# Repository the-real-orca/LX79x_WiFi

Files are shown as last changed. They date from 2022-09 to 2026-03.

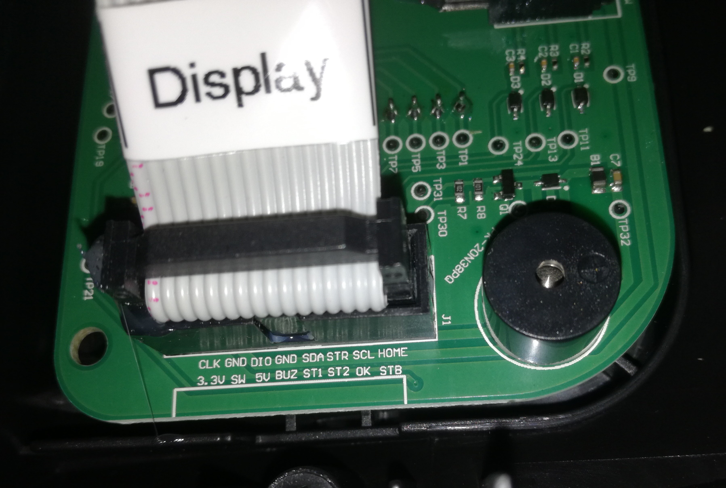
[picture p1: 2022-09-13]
pic/LX790 V1.1/DisplayPCB_1.jpg

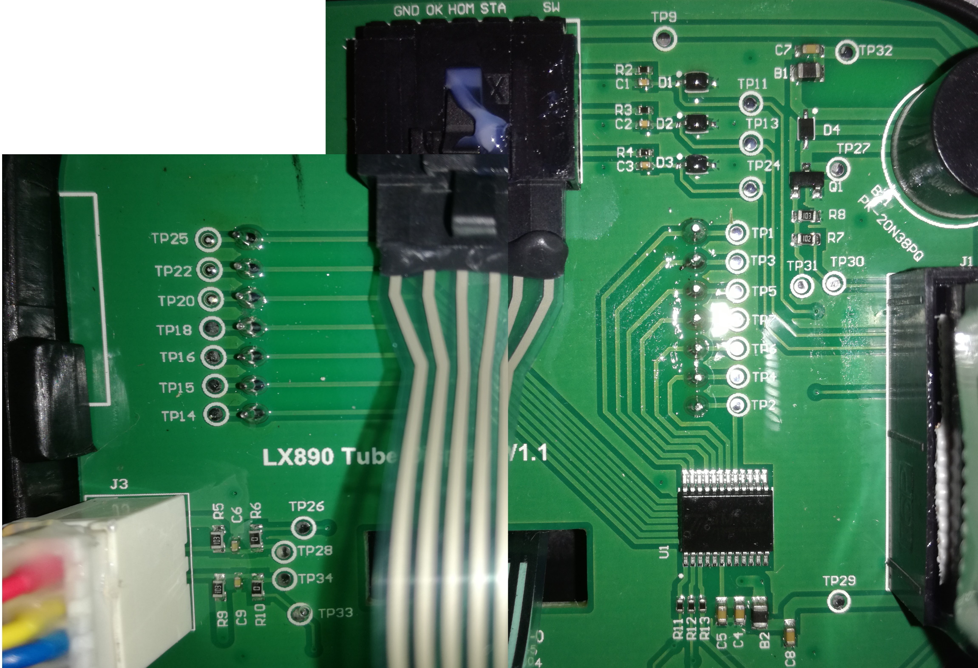
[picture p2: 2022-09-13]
pic/LX790 V1.1/DisplayPCB_2.jpg

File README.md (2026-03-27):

# LX79x Mähroboter WiFi Erweiterung mit ESP32

Nachrüstung einer WiFi Schnittstelle mit Websteuerung für einen LandXcape LX79x Mähroboter

*Der Einsatz von diesem Projekt erfolgt auf eigene Gefahr! Der Ersteller kann nicht für Schäden haftbar gemacht werden. Sie können einen Verlust der Garantie und des Supports durch den Hersteller riskieren! Dieses Projekt ist keine offizielle Erweiterung des Roboters!*

<p align="center">
  
  
</p>

### Allgemein
- Fernauslesen des Displays
- Klartextausgabe der Fehlercodes
- Fernsteuern der Tasten und Funktionen
- Anbindung über den I2C Bus zwischen Display und Mainboard
- Wenn der Roboter in der Ladestation steht uns aus ist, kann dieser mit "I/O" eingeschaltet werden

### Voraussetzungen
#### Hardware
Zum Einsatz kommt der ESP32 auf dem Board "DOIT ESP32 DEVKIT V1". Dieser wurde gewählt, da er zwei Hardware I2C Schnittstellen besitzt. Das ist wichtig, da beim I2C Bus des Roboters das Timing nicht zu sehr beeinflusst werden darf.

##### Anbindung an den I2C Bus
Um den ESP32 in den I2C Bus zwischen Mainboard und Display zwischenschalten zu können, benötigt man ein Adapterkabel. Dabei muss am Roboter selbst nichts "umgebaut" werden. Es wird lediglich der Stecker des Displays ausgesteckt und ein Adapter wie folgt dazwischen gesteckt:
<p align="center">
  
  
    
    
    
    
    
</p>

Das Adapterkabel hat eine Gesamtlänge von ca 70cm.

##### Platine
Der ESP32 wird auf eine Lochrasterplatine Adaptiert. Die fertige Platine kann dann in dem Batteriefach eingebaut werden.
<p align="center">
  
  
  
  
</p>

[Gesamter Schaltplan als PDF](pic/Schaltplan.pdf)

#### Software
Um den ESP32 programmieren und flashen zu können, wurde in diesem Projekt die Arduino IDE eingesetzt.

##### Folgende Voraussetzungen müssen dafür geschaffen werden:
1. Installation der aktuellen Arduino IDE
2. ESP32 Core installieren (https://docs.espressif.com/projects/arduino-esp32/en/latest/installing.html)
3. Boardtyp auswählen: 'Werkzeuge->Board->DOIT ESP32 DEVKIT V1'
4. CRC Bibliothek ergänzen: 'Werkzeuge->Bibliotheken verwalten...->CRC (Rob Tillaart)'
5. Filesystem Uploader: (https://randomnerdtutorials.com/install-esp32-filesystem-uploader-arduino-ide/)
  1. Download ESP32FS ZIP: https://github.com/me-no-dev/arduino-esp32fs-plugin/releases/
  2. ZIP direkt in "c:\Program Files (x86)\Arduino\tools\" entpacken
  3. Arduino IDE neu starten

##### ESP32 flashen/Programm und Daten uploaden:
1. Repository herunterladen und "ino" Projektdatei öffnen
2. ESP32 Board per USB verbinden und passende COM Schnittstelle auswählen: 'Werkzeuge->Port'
3. Im .ino Code die WiFi Zugangsdaten anpassen:
```c
const char* ssid     = "DEINESSID";
const char* password = "DEINPASSWORT";
```
4. Ordner "data" mit 'Werkzeuge->ESP32 Sketch Data Upload' hochladen
5. Seriellen Monitor öffnen
6. Projekt kompilieren und hochladen
7. Über Seriellen Monitor kontrollieren ob WiFi Verbindung besteht und IP Adresse, welche vom DHCP Server vergeben wurde, ermitteln bzw. merken.

### Anwendung
#### Webbrowser
Das Webinterface kann direkt mit der IP Adresse aufgerufen werden:
<p align="center">
  
</p>

#### HTTP Anfragemethoden
##### Befehle Senden
http://MOWERADRESS/cmd?parm=[COMMAND]&value=[VALUE]

param=[COMMAND]:

- start -> Taste Start bzw. hoch
- home -> Taste Home bzw. runter
- ok -> Taste Ok
- stop -> Taste Stop
- workzone -> Arbeitsbereich einstellen
- timedate -> Zeit und Datum einstellen
- startmow -> "Mähen" starten
- homemow -> "Zurück zur Ladestation" starten

value=[VALUE]:

- Bei "start, home, ok, stop" ist [VALUE] die Dauer in ms des Tastendrucks ansonsten muss 1 übergeben werden.

>Beispiel - die Taste Start soll 5 Sekunden gedrückt werden:
>
>http://MOWERADRESS/cmd?parm=start&value=5000

##### Zustand Abfragen
http://MOWERADRESS/statval

Antwort:
[Display];[RSSI];[Batteriestatus];[Klartext]

>Beispiel bei Fehler:
>
>-E8-;-83;off;Es dauert zu lange, bis der Robi zur Ladestation zurückkehrt.
>
>Beispiel während dem Mähen:
>
>|--|;-80;mid;Mähen...

##### Beispiel
Einbindung in FHEM per HTTPMOD:

```
defmod MRoboter HTTPMOD none 5
attr MRoboter alias MRoboter
attr MRoboter event-on-change-reading .*
attr MRoboter get01-1Name Display
attr MRoboter get01-2Name RSSI
attr MRoboter get01-3Name Battery
attr MRoboter get01-4Name Status
attr MRoboter get01Decode UTF-8
attr MRoboter get01Name Ouput
attr MRoboter get01Poll 1
attr MRoboter get01Regex (\N+);;(\N+);;(\N+);;(\N+)
attr MRoboter get01URL http://192.168.2.54:80/statval
attr MRoboter group Mähroboter
attr MRoboter room Haus
attr MRoboter showBody 1
attr MRoboter stateFormat D: Display WL: RSSI S: Status B: Battery
```

Eine Aufzeichnung sieht dann so aus:

<p align="center">
  
</p>

##### Update ausführen
http://MOWERADRESS/update

Damit kann eine .bin Datei auf den ESP32 hochgeladen werden.

---

### Entwicklung mit Docker
Für eine konsistente Build-Umgebung steht ein Docker-Setup zur Verfügung. Dies ist besonders nützlich, wenn man keine lokale Arduino IDE oder PlatformIO Installation pflegen möchte.

Details zur Einrichtung und Verwendung finden sich in der [docker_setup.md](docker_setup.md).

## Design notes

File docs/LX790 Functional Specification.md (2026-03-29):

# Funktionale Spezifikation (FSD) - LX790 WiFi Erweiterung

## 1. Übersicht

### 1.1 Zweck
Das LX790 WiFi Erweiterungsprojekt dient der Nachrüstung eines LandXcape LX79x Mähroboters mit einer WLAN-Schnittstelle. Ziel ist es, den Mähroboter aus der Ferne zu überwachen, zu steuern und in bestehende Smart-Home-Systeme zu integrieren.

### 1.2 Umfang
Enthalten sind die Echtzeit-Überwachung des Displays, die Fernsteuerung der Tasten, WLAN-Konnektivität und OTA-Updates. Ausgeschlossen ist der direkte Eingriff in die Motorsteuerung oder Sensordaten des Mähers.

### 1.3 Benutzer / Rollen
- Admin: Konfiguriert WLAN-Einstellungen und führt Firmware-Updates durch.
- Nutzer: Überwacht den Status des Mähers und nutzt die Fernsteuerung.

## 2. Funktionale Zusammenfassung

### 2.1 Hauptablauf / Betriebsmodi
- Normaler Modus: ESP32 ist mit dem Heim-WLAN verbunden und überträgt Daten.
- Konfigurations-Modus: Captive Portal zur Ersteinrichtung bei fehlender Verbindung.
- Debug-Modus: Erweiterte Protokollierung von Hardware-Signalen.

### 2.2 Systemarchitektur
```
┌──────────────────────────────────────────────────────────────────────────┐
│                          Netzwerk (WLAN)                                 │
└──────────────────────────────────────────────────────────────────────────┘
       │                                           │
       ▼                                           ▼
┌────────────────────────┐              ┌────────────────────┐
│  Mähroboter (LX790)    │              │  Benutzeroberfläche│
│  ┌──────────────────┐  │              └────────────────────┘
│  │ Display / Tasten │  │
│  └──────────────────┘  │
│          ▲             │
│          │ Sniffing    │
│  ┌──────────────────┐  │
│  │ ESP32 Erweiterung│  │
│  └──────────────────┘  │
└────────────────────────┘
```

### 2.3 Hardwarebeschreibung
- Zentraleinheit: ESP32 Mikrocontroller.
- Display-Schnittstelle: TM1668 Controller (3-Draht-SPI).
- Tasten-Interface: GPIO-Anbindung zur Simulation von Tastendrücken.

### 2.4 Kernkomponenten
- Display-Decoder: Dekodiert TM1668 Segmente in Klartext.
- Button-Injector: Steuert die GPIOs zur Tasten-Simulation.
- Web-Server: Stellt das Interface und die REST-API bereit.

## 3. Definitionen

### 3.1 Begriffe und Abkürzungen

| Name | Beschreibung |
|---|---|
| TM1668 | LED-Controller für Anzeige und Tasten. |
| Sniffing | Passives Mitlesen des Datenbusses. |
| OTA | Firmware-Update über WLAN (Over-the-Air). |

## 4. Funktionale Anforderungen

### 4.1 Status-Überwachung (FR-001)
Das System zeigt den aktuellen Inhalt des 7-Segment-Displays und die Symbole in Echtzeit an.

 - **Auslöser:** kontinuierlich

 - **Verhalten:**
   - Der ESP32 dekodiert die Segmente und Symbole (Batterie, Uhr, Schloss)
   - Der ESP32 aktualisiert den internen System-Status

 - **Erwartetes Ergebnis:**
   - Die Weboberfläche spiegelt den exakten Inhalt des physischen Displays wider

### 4.2 Fernsteuerung der Tasten (FR-002)
Simulation der Tasten Start, Home, OK und Stop.

 - **Auslöser:** Benutzerinteraktion in der Weboberfläche oder API-Aufruf.

 - **Verhalten:**
   - Der entsprechende GPIO wird kurzzeitig als Ausgang (LOW) geschaltet
   - Das System simuliert einen physischen Tastendruck

 - **Erwartetes Ergebnis:**
   - Der Mähroboter reagiert so, als wäre die physische Taste manuell gedrückt worden

### 4.3 Automatisches Entsperren (FR-003)
Automatische Eingabe des PIN-Codes, wenn der Mäher gesperrt ist.

 - **Auslöser:** Detektion des Sperr-Symbols oder des PIN-Eingabe-Displays ("0---").

 - **Verhalten:**
   - Das System prüft ob der Mäher automatisch entsperrt werden soll (`config.json`)
   - Wenn ja, liest es die hinterlegte PIN aus der Konfiguration
   - Das System sendet die PIN als Sequenz virtueller Tastendrücke

 - **Erwartetes Ergebnis:**
   - Der Mäher wechselt automatisch in den entsperrten Zustand

### 4.4 WLAN-Konfiguration (FR-004)
Verwaltung der WLAN-Zugangsdaten und des Captive Portals.

 - **Auslöser:** 
   - Erststart oder fehlende Verbindung zum Netzwerk.
   - press "HOME" button for 10 seconds to start captive portal

 - **Verhalten:**
   - Start des Access Points
   - DNS-Umleitung aller Anfragen zur Konfigurationsseite

 - **Erwartetes Ergebnis:**
   - Nutzer kann neue Zugangsdaten speichern und das System verbindet sich neu

## 5. Nicht-funktionale Anforderungen

### 5.1 Echtzeitfähigkeit (NFR-001)
Die Verzögerung zwischen physischem Display und Web-Anzeige muss minimal sein.

**Erwartetes Ergebnis:**
- Die Latenz der Statusaktualisierung liegt unter 500ms

### 5.2 Zuverlässigkeit (NFR-002)
Das System darf den normalen Betrieb des Mähers bei Fehlfunktion des ESP32 nicht stören.

**Erwartetes Ergebnis:**
- Der Mäher bleibt auch bei Ausfall des ESP32 manuell bedienbar

## 6. Daten
- Quelle: TM1668 Bus via ESP32 Sniffing
- Format: JSON Objekt via /status API
- Speicherung: Konfiguration in config.json auf SPIFFS

## 7. Benutzeroberfläche

### 7.1 Dashboard
Hauptseite zur Überwachung und Steuerung.
- Replikation des Displays
- Steuerungstasten und Makros
- Statusanzeigen für Batterie und System

## 8. Testfälle

### 8.1 Display-Replikation (TC-001)
1. Ändere den Zustand des Mähers (z.B. Stop drücken)
2. Überprüfe die Anzeige in der Weboberfläche

 - **Erfolgskriterien:**
   - Die Weboberfläche zeigt den korrekten Status (z.B. -E1-)

 - **Verknüpfte Anforderungen:** FR-001

### 8.2 Remote-Start (TC-002)
1. Betätige den Button "Mähen starten" in der Weboberfläche

 - **Erfolgskriterien:**
   - Der Mähroboter piept und startet den Mähvorgang

 - **Verknüpfte Anforderungen:** FR-002

## 9. Offene Punkte / Annahmen

### 9.1 Offene Fragen
- Ladeerkennung: Unterscheidung zwischen DOCKED und CHARGING unzuverlässig.
- Auto-Unlock: Validierung bei unterschiedlichen Firmware-Ständen des Mähers.

### 9.2 Annahmen
- Stabile Stromversorgung über die interne 5V Schiene.
- TM1668 Protokoll ist konsistent über die gesamte LX79x Serie.

## Anhang A: Technische Details
Detaillierte Informationen zur Architektur, den Quellcodedateien und der Pin-Belegung finden Sie in der technischen Spezifikation:
[LX790 Technical Specification.md](LX790%20Technical%20Specification.md)

## Anhang B: Implementierungsplan
Den aktuellen Status der Umsetzung sowie geplante Aufgaben finden Sie im Implementierungsstatus:
[LX790 Implementation Status.md](LX790%20Implementation%20Status.md)

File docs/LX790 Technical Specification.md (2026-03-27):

# Technical Specification - LX790 WiFi Extension

## 1. System Architecture
The system is built on an ESP32 microcontroller using the Arduino framework with FreeRTOS for multi-tasking. It intercepts the communication between the mower's mainboard and the display unit. It uses a dual-core approach to separate timing-critical hardware sniffing from the network stack.

### 1.1 Task Structure
The application is divided into two main FreeRTOS tasks pinned to different cores:

- **TaskHW (Core 0)**: 
    - Handles low-level hardware communication (TM1668 sniffing, button injection).
    - Manages WiFi connectivity (Station mode & Captive Portal).
    - Processes the command queue (`cmdQueue`).
    - Updates the system state and sends it to `stateQueue`.
- **TaskWeb (Core 1)**:
    - Hosts the asynchronous web server.
    - Serves static files from SPIFFS.
    - Provides a REST API for status monitoring and command execution.
    - Manages UI updates and system logging.

## 2. Source File Overview

| File | Description | Key Functions / Interfaces |
|---|---|---|
| `LX790_ESP32.ino` | Main entry point. Initializes Serial, SPIFFS, and launches FreeRTOS tasks. | `setup()`, `loop()` |
| `TaskHW.cpp` | Core logic for hardware interaction and WiFi management. | `TaskHW()`, manages `stateQueue` and `cmdQueue`. |
| `TaskWeb.cpp` | Implementation of the web server and REST API. | `TaskWeb()`, `Web_getCmd()`, `Web_aktStatusWeb()`, `jsonStatus()`. |
| `HAL_LX790.h` | Generic HAL interface. Includes version-specific headers. | `HAL_setup()`, `HAL_loop()`, `HAL_buttonPress()`, `HAL_buttonRelease()`. |
| `HAL_LX790_V1_0.cpp/h` | HAL for V1.0 hardware (using I2C sniffing). | Implements hardware communication for older models. |
| `HAL_LX790_V1_1.cpp/h` | HAL for V1.1 hardware (using TM1668 SPI sniffing). | TM1668 bit-banging and signal interception logic. |
| `LX790_util.cpp/h` | Utility functions for data decoding and command queueing. | `decodeChar()`, `encodeSeg()`, `decodeDisplay()`, `queueButton()`. |
| `FileBrowser.cpp/h` | SPIFFS file management for the web interface. | `handleFileRead()`, `handleFileUpload()`, `handleFileDelete()`. |
| `ahWireSlave.cpp/h` | Custom I2C slave driver for ESP32 (used in V1.0). | `TwoWireSlave::begin()`, `read_buff()`, `write_buff()`. |
| `config.h` | Global configuration, model selection, and debug flags. | `LX790_Config` struct, `HW_MODEL` define. |

## 3. Hardware Components

### 3.1 Microcontroller (ESP32)
- Dual-core 240MHz Xtensa® LX6.
- Integrated WiFi/Bluetooth.
- Utilizes SPIFFS for web resource storage and EEPROM/Preferences for persistent configuration.

### 3.2 Hardware Abstraction Layer (HAL)
A polymorphic HAL allows supporting different hardware versions (V1.0 and V1.1):
- `HAL_LX790_V1_0`: Original implementation using I2C slave mode to listen to display updates.
- `HAL_LX790_V1_1`: Updated pin mapping and logic for version 1.1 hardware using TM1668 SPI sniffing.

### 3.3 Display Controller Sniffing (TM1668)
The ESP32 "sniffs" the SPI-like protocol used by the TM1668 display controller:
- **Signals**: CLK (Clock), DIO (Data), STB (Chip Select).
- **Protocol**: 3-wire serial interface, LSB first.
- **Method**: The HAL identifies `DISPLAY_CMD_ADDRESS (0xC0)` to capture segment data for the 4 digits and additional symbols (Battery, Clock, Lock).

### 3.4 Button Injection
Remote control is achieved by pulling physical button lines to GND via ESP32 GPIOs:
- **Buttons**: Power/IO, Start (Up), Home (Down), OK, Stop.
- **Method**: GPIOs are configured as `INPUT` (high impedance) when inactive and `OUTPUT LOW` to simulate a press.

## 4. Communication & Data Flow

### 4.1 Inter-Task Communication
- **`stateQueue`**: A FreeRTOS queue (`QueueHandle_t`) used to push `LX790_State` updates from `TaskHW` (Core 0) to `TaskWeb` (Core 1).
- **`cmdQueue`**: A FreeRTOS queue used to send `CMD_Type` commands from the Web/Serial interface to the hardware task.
- **`queueButton(BUTTONS btn, int delay)`**: Helper function that sequences a `BTN_PRESS`, a `WAIT`, and a `BTN_RELEASE` into the `cmdQueue`.

### 4.2 External Interfaces
- **Web UI**: Responsive HTML/JS interface served from SPIFFS.
- **REST API**: 
    - `GET /status`: Returns full state as JSON (generated by `jsonStatus()`).
    - `GET /cmd?parm=[BTN]&value=[0/1]`: Executes button presses or system commands.
- **Serial Console**: 115200 baud, supports manual configuration (`config`), reboot, and WiFi mode switching (`portal`, `client`).

## 5. Software Stack
- **Framework**: Arduino ESP32.
- **JSON Library**: ArduinoJson (v7.x).
- **Web Server**: WebServer (built-in) / ESP32 Web Server logic.
- **Storage**: SPIFFS for files (Web UI, logs), EEPROM for settings (debugLog, autoUnlock).
- **Other**: DNSServer for Captive Portal, mDNS for hostname resolution, ezTime for NTP sync.

## 6. Pin Mapping (V1.1 Example)
| Function | ESP32 Pin | Signal | Cable Pin |
|---|---|---|---|
| CLK | D14 | Clock  | #2 |
| DIO | D13 | Data | #6 |
| STB | D15 | CS | #15 |
| OK | D33 | Button | #13 |
| START | D25 | Button | #12 |
| HOME | D32 | Button | #16 |
| STOP | D26 | Button | #9 & #11  |
| SW (IO)  | D27 | Button | #3 |

## 7. Implementation Details
- **TM1668 Decoding**: Raw segment data is converted into ASCII characters via a lookup table (`decodeChar`) in `LX790_util.cpp`.
- **Mode Detection**: The system analyzes display patterns and system flags to infer the mower's state (Mowing, Charging, Error, etc.).
- **Auto-Unlock**: A state machine in `TaskHW` can automatically sequence the PIN entry if the `lock` flag is detected on the display.
- **Logging**: `TaskWeb` manages rotating logs (`system.log`, `debug.log`) stored in SPIFFS, capturing state changes and debug information.

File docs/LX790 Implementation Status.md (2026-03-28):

# Abgleich FSD vs. Implementierung (LX790 WiFi Extension)

Diese Liste gibt einen Überblick über den Erfüllungsgrad der im Functional Specification Document (FSD) definierten Anforderungen.

## 1. Status-Überwachung
| Funktion | Status | Anmerkung |
|---|---|---|
| Display-Replikation | **OK** | 7-Segment Dekodierung in `LX790_util.cpp` implementiert. |
| Statussymbole (Uhr, Schloss) | **OK** | Symbole werden im Web UI und im State-Objekt korrekt verarbeitet. |
| WLAN-Status Symbol | **Entfällt** | Gemäß FSD (3.1) nicht angezeigt, da Web-Verbindung WLAN voraussetzt. |
| Batteriestand | **OK** | 4-stufige Anzeige im Web UI integriert. |
| Ladezustand (Laden) | **Fehlerhaft** | In `LX790_util.cpp:261` steht ein `FIXME`, das den Modus hart auf `DOCKED` überschreibt, da die Lade-Erkennung unzuverlässig ist. |
| Klartext-Status (Fehlercodes) | **OK** | Umfangreiche Mapping-Tabelle `LcdToMode` in `LX790_util.cpp`. |

## 2. Fernsteuerung
| Funktion | Status | Anmerkung |
|---|---|---|
| Virtuelle Tasten (Start, Home, OK, Stop) | **OK** | Alle Tasten über `/cmd?parm=...` erreichbar. |
| Makro "Mähen starten" | **OK** | START + OK Sequenz. |
| Makro "Zur Ladestation" | **OK** | HOME + OK Sequenz. |
| PIN Vergabe (Makro) | **OK** | START + HOME (8s) Makro zum Start der PIN-Änderung am Mäher. |

## 3. Konnektivität & Konfiguration
| Funktion | Status | Anmerkung |
|---|---|---|
| WLAN Client-Modus | **OK** | In `TaskHW.cpp` und `config.json` implementiert. |
| Captive Portal / AP | **OK** | In `TaskHW.cpp` und `config.json` implementiert. |
| Web-Interface | **OK** | Responsives UI (`index.html`, `config.html`) vorhanden. |
| mDNS Support | **OK** | `MDNS.begin()` mit konfigurierbarem Namen. |

## 3.4 System-Konfiguration (`config.html`)
| Funktion | Status | Anmerkung |
|---|---|---|
| Gerätename | **OK** | Hostname wird aus `config.json` geladen. |
| PIN-Hinterlegung | **OK** | PIN für Auto-Unlock wird in `config.json` gespeichert. |
| WLAN-Settings | **OK** | SSID/Passwort in `config.json`. |
| Portal-Settings | **OK** | Aktivierung, Passwort und Timeout in `config.json`. |

## 3.5 Betriebs- & Systemeinstellungen (`index.html`)
| Funktion | Status | Anmerkung |
|---|---|---|
| Auto-Unlock | **Teilweise** | Schalter vorhanden, Speicherung im EEPROM. PIN-Eingabe-Logik experimentell. |
| Mäher-Konfiguration | **OK** | Makros für Arbeitsbereich, Zeit/Datum, PIN-Änderung, Startzeit. |
| Reboot | **OK** | Über `/cmd?parm=reboot` möglich. |
| OTA-Updates | **OK** | Über `/update` implementiert. |
| Dateisystem (Upload) | **OK** | Upload von Web-Ressourcen in der `update.html` integriert. |
| Debug-Logging | **OK** | Schalter vorhanden, Speicherung im EEPROM. Log via `/debuglog`. |

## Liste der fehlenden oder inkorrekt implementierten Funktionen:

1.  **Ladezustands-Erkennung (Kritisch):** Die Unterscheidung zwischen `LX790_DOCKED` (nur in Station) und `LX790_CHARGING` (lädt aktiv) ist unzuverlässig und wird derzeit unterdrückt. (Fokus V1.1)
2.  **Auto-Unlock Robustheit:** Die Logik verlässt sich auf Display-Muster, die je nach Firmware variieren können.
3.  **TM1668 SPI-Sniffing Stabilität (Neu - Hohe Priorität):** Instabilitäten bei blinkenden Anzeigen (z.B. Laden). Frames gehen verloren oder Synchronisation (STB/CS) verschiebt sich.

## Roadmap für spätere Umsetzung

### Task 1: TM1668 Robustheit & SPI-Sniffing (V1.1 Spezifisch)
- **1.1 Rohdaten-Analyse:** Implementierung eines temporären "Raw-Dump"-Modus, um die exakten Byte-Sequenzen während des Blinkens zu loggen.
- **1.2 Synchronisations-Check:** Überprüfung, ob `ESP32SPISlave` korrekt auf die fallende Flanke von `STB` reagiert. Ggf. Hardware-Interrupt am `STB`-Pin.
- **1.3 Buffer-Management:** Evaluierung der `spi_slave_rx_buf_size` und sichere Identifikation des Command-Bytes am Frame-Anfang.
- **1.4 Validitäts-Prüfung:** Einführung einer Validierung für jeden empfangenen Frame.
- **1.5 Persistence Filter (Anti-Flicker):** Softwareseitiger Filter, der Zustände erst nach N stabilen Frames übernimmt.
- **1.6 Blink-Erkennung:** Spezielle Logik für das Batterie-Symbol zur stabilen `LX790_CHARGING` Erkennung.
- **1.7 CPU-Affinität & Interrupts:** Optimierung der Task-Prioritäten und Prüfung von SPI-DMA zur Lastreduzierung.
- **1.8 TM1668 Bit-Mapping:** Identifikation der exakten Bits für die Ladeanimation.
- **1.9 Status-Mapping:** Korrektur der `state.battery`-Logik zur korrekten Stufendarstellung (0-3).

### Task 2: Analyse und Verbesserung der Ladezustands-Erkennung (Kritisch)
Die aktuelle Implementierung in `LX790_util.cpp` überschreibt den Status hart mit `DOCKED`, da die Erkennung unzuverlässig ist.
- **2.1:** Untersuchen der Rohdaten vom TM1668/I2C-Bus während des Ladevorgangs und im gedockten Zustand.
- **2.2:** Identifizieren von Mustern (z.B. blinkendes Batterie-Symbol oder spezifische Spannungsänderungen, falls verfügbar).
- **2.3:** Implementierung einer robusteren Logik in `decodeDisplay` (Version 1.0) bzw. `decodeTM1668` (Version 1.1).
- **2.4:** Entfernen des `FIXME`-Kommentars und Validierung des Zustandsübergangs.

### Task 3: Optimierung der Auto-Unlock Logik
Die Auto-Unlock Logik muss zuverlässiger auf verschiedene Display-Zustände reagieren.
- **3.1:** Testen der PIN-Eingabe-Erkennung bei verschiedenen Startbedingungen (z.B. nach Manuellem Stop vs. nach Einschalten).
- **3.2:** Einführen eines Timeout-Mechanismus für Fehlversuche, um Endlosschleifen bei falscher PIN zu vermeiden.
- **3.3:** Sicherstellen, dass die Logik auch bei zeitversetzter Anzeige (Scrolling) korrekt greift.

### Task 4: Code-Qualität und Stabilität
- **4.1:** Überprüfung der Thread-Sicherheit beim Zugriff auf `LX790_State` zwischen `TaskHW` und `TaskWeb`.
- **4.2:** Implementierung eines Watchdog-Mechanismus für die HW-Kommunikation (besonders I2C Slave in V1.0), um Hänger abzufangen.
- **4.3:** Finalisierung der `@TODO`-Markierungen in `HAL_LX790_V1_0.cpp` bezüglich der Trennung von Read- und Write-Sektionen.

### Task 5: Erweiterung der Web-Oberfläche
- **5.1:** Anzeige der Signalstärke (RSSI) im Web-UI (Daten sind im JSON bereits vorhanden).
- **5.2:** Optionale Anzeige der letzten Log-Einträge direkt auf dem Dashboard (statt nur Download).
- **5.3:** Hinzufügen einer visuellen Rückmeldung (z.B. Spinner), wenn ein Makro (PIN, Startmow) ausgeführt wird.

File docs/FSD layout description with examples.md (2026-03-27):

# Functional Specification Document

## 1. Overview

### 1.1 Purpose

- Business problem or goal  
- Why this system or feature exists  
- Expected business value  

**Example:**  
Enable remote monitoring of IoT devices to reduce manual maintenance effort.

### 1.2 Scope

- What is included  
- What is explicitly excluded  
- Functional boundaries of the system  

**Example:**  
Includes device status monitoring and alerting. Excludes firmware updates and device provisioning.

### 1.3 Users / Roles

- User groups interacting with the system  
- Their responsibilities and level of access  

**Example:**  
- Admin: configures the system and manages users  
- Operator: monitors device status and handles alerts  
- Viewer: has read-only access  

## 2. Functional Summary

### 2.1 Main Workflow / Operating Modes

- Main system workflow  
- Main operational states or modes  
- High-level process overview  

**Example:**  
- Normal mode: system collects and displays device data  
- Debug mode: system outputs additional diagnostic information  

### 2.2 System Architecture

- High-level system structure  
- Main software and hardware components  
- Component interactions and system boundaries  

**Example:**  
```
┌──────────────────────────────────────────────────────────────────────────┐
│                          Network (192.168.0.x)                           │
└──────────────────────────────────────────────────────────────────────────┘
       │  eth0 (USB Ethernet)                      │
       │                                           │
       ▼                                           ▼
┌────────────────────────┐              ┌────────────────────┐
│  VM Host               │              │  IoT Device        │
│                        │              └────────────────────┘
│  ┌──────────────────┐  │
│  │ Container A      │  │
│  │ - Web Server     │  │  
│  │ - Backend API    │  │  
│  └──────────────────┘  │  
│  ┌──────────────────┐  │
│  │ Container B      │  │
│  │ - DB             │  │  
│  └──────────────────┘  │  
│  ┌──────────────────┐  │
│  │ Container C      │  │
│  │ - Device Monitor │  │  
│  └──────────────────┘  │  
└────────────────────────┘
```

### 2.3 Hardware Description

- Dedicated computing hardware  
- External devices  
- Relevant hardware interfaces  
- System boundaries, if applicable  

**Example:**  
- Server: Linux VM  
- Devices: ESP32 sensors  
- Network: Ethernet and Wi-Fi communication  

### 2.4 Key Components

- Core software and hardware components  
- Purpose of each major component  

**Example:**  
- Web Server: serves the user interface  
- Database: stores device data and system state  
- Backend API: provides REST endpoints for the web application  
- Device Monitor: monitors IoT devices and updates the database  

## 3. Definitions (optional)

### 3.1 Terms and Abbreviations

- Domain-specific terms  
- Abbreviations used throughout the document  

**Example:**

| Name | Description |
|--|-|
| Device | IoT HW device sending data |
| Alert  | Notification triggered by a threshold breach |

## 4. Functional Requirements

- List of functional requirements  
- One requirement per subsection  
- Title format: `<requirement name> (FR-xxx)`  

Each functional requirement should contain:
- Description: What the system must do  
- Trigger: What starts the action  
- Behavior: Expected system behavior  
- Expected Result: Clear, testable outcome  

**Example:**

### 4.1 Status Overview (FR-001)

Description:  
The system displays the current status of all devices.

Trigger:  
The user opens the dashboard.

Behavior:
- The system retrieves device data  
- The system displays the status of each device  
- Status values include online, offline, and error  

Expected Result:
- All devices are listed  
- Status updates are visible within 5 seconds  
- Offline devices are clearly marked  

## 5. Non-Functional Requirements

- List of non-functional requirements  
- One requirement per subsection  
- Focus on quality attributes and operational constraints (e.g. performance, reliability, security, maintainability, determinism)

**Example:**

### 5.1 Determinism (NFR-001)

Description:  
The system behaves predictably across restarts and deployments.

Expected Result:
- Configuration survives reboots  
- No dynamic IP assignment is used  

## 6. Data

- Main data flow  
- Data sources and destinations  
- Data formats  
- Validation rules  
- Storage or persistence, if relevant  

**Example:**  
- Source: IoT devices via MQTT  
- Format: JSON {device_id, temperature, timestamp}  
- Validation: temperature must be within -40 to 125°C  
- Storage: validated data is stored in the database  

## 7. User Interface

- UI structure and behavior  
- Screens, views, and interactions  
- One subsection per page or major view  

**Example:**

### 7.1 Dashboard

Overview page showing all devices.
- device list  
- current device status  
- active alerts  
- quick navigation to detail views  

## 8. External Dependencies / Integrations

- External systems or services  
- Interfaces and exchanged data  
- High-level integration behavior  

**Example:**

### 8.1 Email Service

The system is connected to an external mail server for notifications.
- Mail server: example.com  
- Protocol: SMTP  
- Usage: alert notifications  

## 9. Permissions (if relevant)

- Access control rules  
- Who can view, create, edit, delete, approve, or administer  

**Example:**  
- Admin: full access  
- Operator: read access and alert acknowledgement  
- Viewer: read-only access  

## 10. Test Cases

- Key scenarios for validation  
- One test case per subsection  
- Title format: `<test case name> (TC-xxx)`  

Each test case should contain:
- Steps: What actions are performed  
- Related Requirements: Linked requirement IDs  
- Pass Criteria: Clear yes/no criteria  

**Example:**

### 10.1 Device Registration (TC-001)

Steps:
1. A new IoT device is added to the network  
2. The device registers itself with the system  

Pass Criteria:
- A new entry for the device is created in the database  

Related Requirements:
- FR-001  

## 11. Open Points / Assumptions

### 11.1 Open Questions

- Unclear or unresolved points  
- Issues that still need a decision  

**Example:**  
- Should alerts be persisted after restart?  

### 11.2 Assumptions

- Assumptions about external systems or expected behavior  

**Example:**  
- Devices send data every 10 seconds  
- Network connectivity is available during normal operation  

## Appendix A: Technical Details

## Appendix B: Implementation Plan

### B.1 Implementation Plan

- Implementation steps and planned tasks  

**Example:**  
- [x] Implement device ingestion service  
- [ ] Build dashboard UI  
- [ ] Add alert notification workflow

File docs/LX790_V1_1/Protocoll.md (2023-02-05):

LX890 V1.1
==========

Display Cable
-------------

| | | | | |
|---:|-:|:-:|:-:|---|
**3v3** (Opto supply)               | | 1 | 2 | **CLK** -> D14 #2 (brown)
**SW** *(I/O Btn)* -> Opto -> D27 #- (orange) | | 3 | 4 | **GND** -> GND #3 (black)
**5V** -> Vin #1 (red)              | | 5 | 6 | **DIO** *(Data)* -> D13 #4 (white)
**BUZ**                         |**[**| 7 | 8 | **GND** (Opto supply)
**ST1** *(Stop)* --> **ST2**    |**[**| 9 | 10| **SDA** *(I2C)*
*(Stop)* -> D26 #5 (gray)           | | 11| 12| **STR** *(Start Btn)* -> D25 #6 (violet)
**OK** *(OK Btn)* -> D33 #7 (blue)  | | 13| 14| **SCL** *(I2C)*
**STB** *(CS)* -> D15 #8 (green)    | | 15| 16| **HOME** *(Home Btn)* -> D32 #9 (yellow)

Stop Button Cable
-----------------

 - JIABEN FA7-6K-2100 Trigger switch
 - 5V 1mA
 - DPNO Hall Signal

cable   | 1    | 2    | 3    | 4    
--------|:----:|:----:|:----:|:----:
color   | red  |yellow| blue |black 
signal  | 3v3  | ST1  | ST2  | GND  
release |      | 0V   | 0V   |
press   |      | 3v3  | 3v3  |

Power Off
---------

	SW: 20V
	all other: 0V

Power On
----------

	SW: 3V (released) / 0V (pressed)
	OK: 3V (released) / 0V (pressed)
	STR: 3V (released) / 0V (pressed)
	HOME: 3V (released) / 0V (pressed)
	BUZ: 0V / 3V @ 2.5kHz
	ST1 & ST2: 0V (released) / 3V (pressed)

Display Controller: TM1668 
--------------------------

**Display Protocol**

 - SPI mode: 0 / LSB
 - CLK: *Clock 100kHz*
 - DIO: *Data In/Out*
 - STB: *Chip Select*

**Segments**

	 -- 1 --
	|       |
	6       2
	|       |
	 -- 7 --
	|       |
	5       3
	|       |
	 -- 4 --
 
 - SEG1 0x01
 - SEG2 0x02
 - SEG3 0x04
 - SEG4 0x08
 - SEG5 0x10
 - SEG6 0x20
 - SEG7 0x40

**Examples**

*"-E6-"*

| Seq. | Raw | Command Description |
---|-----|--
 1.1 | 88 / 8E | Display Control: dimmed / bright
|
 2.1 | 03 | Mode Setting: 7 Grids, 11 Segments
|
 3.1 | 40 | Data Setting: write, auto increment, normal operation
 |
 4.1 | C0 | Address Setting: 0
 4.2 | 66 | 
 4.3 | 00 |
 4.4 | 60 |
 4.5 | 00 |
 4.6 | 64 |
 4.7 | 00 |
 4.8 | 26 |
 4.9 | 00 |
 4.10 | 26 |
 4.11 | 00 |
 4.12 | 26 |
 4.13 | 00 |
 4.14 | 0F |
 4.15 | 00 |

*"-E1-"*

| Seq. | Raw | Command Description |
---|-----|--
 1.1 | 8E | Display Control: bright
|
 2.1 | 03 | Mode Setting: 7 Grids, 11 Segments
|
 3.1 | 40 | Data Setting: write, auto increment, normal operation
 |
 4.1 | C0 | Address Setting: 0
 4.2 | 62 | 
 4.3 | 00 |
 4.4 | 64 |
 4.5 | 00 |
 4.6 | 64 |
 4.7 | 00 |
 4.8 | 22 |
 4.9 | 00 |
 4.10 | 22 |
 4.11 | 00 |
 4.12 | 22 |
 4.13 | 00 |
 4.14 | 0B |
 4.15 | 00 |

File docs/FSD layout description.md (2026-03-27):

# Functional Specification Document

## 1. Overview

### 1.1 Purpose

- Business problem or goal
- Why this system or feature exists
- Expected business value

### 1.2 Scope

- What is included
- What is explicitly excluded
- Functional boundaries of the system

### 1.3 Users / Roles

- User groups interacting with the system
- Their responsibilities and level of access

## 2. Functional Summary

### 2.1 Main Workflow / Operating Modes

- Main system workflow
- Main operational states or modes
- High-level process overview

### 2.2 System Architecture

- High-level system structure
- Main software and hardware components
- Component interactions and system boundaries

### 2.3 Hardware Description

- Dedicated computing hardware
- External devices
- Relevant hardware interfaces
- System boundaries, if applicable

### 2.4 Key Components

- Core software and hardware components
- Purpose of each major component

## 3. Definitions (optional)

### 3.1 Terms and Abbreviations

- Domain-specific terms
- Abbreviations used throughout the document

## 4. Functional Requirements

- List of functional requirements
- One requirement per subsection
- Title format: `<requirement name> (FR-xxx)`

Each functional requirement should contain:
- What the system must do
- **Trigger:** What starts the action
- **Behavior:** Expected system behavior
- **Expected Result:** Clear, testable outcome

## 5. Non-Functional Requirements

- List of non-functional requirements
- One requirement per subsection
- Focus on quality attributes and operational constraints (e.g. Performance,  Reliability, Security, Maintainability Determinism)

## 6. Data

- Main data flow
- Data sources and destinations
- Data formats
- Validation rules
- Storage or persistence, if relevant

## 7. User Interface

- UI structure and behavior
- Screens, views, and interactions
- One subsection per page or major view

## 8. External Dependencies / Integrations

- External systems or services
- Interfaces and exchanged data
- High-level integration behavior

## 9. Permissions (if relevant)

- Access control rules
- Who can view, create, edit, delete, approve, or administer

## 10. Test Cases

- Key scenarios for validation
- One test case per subsection
- Title format: `<test case name> (TC-xxx)`

Each test case should contain:
- What actions are performed
- **Related Requirements:** Linked requirement IDs
- **Pass Criteria:** Clear yes/no criteria

## 11. Open Points / Assumptions

### 11.1 Open Questions

- Unclear or unresolved points
- Issues that still need a decision

### 11.2 Assumptions

- Assumptions about external systems or expected behavior

## Appendix A: Technical Details

## Appendix B: Implementation Plan

### B.1 Implementation Plan

- Implementation steps and planned tasks

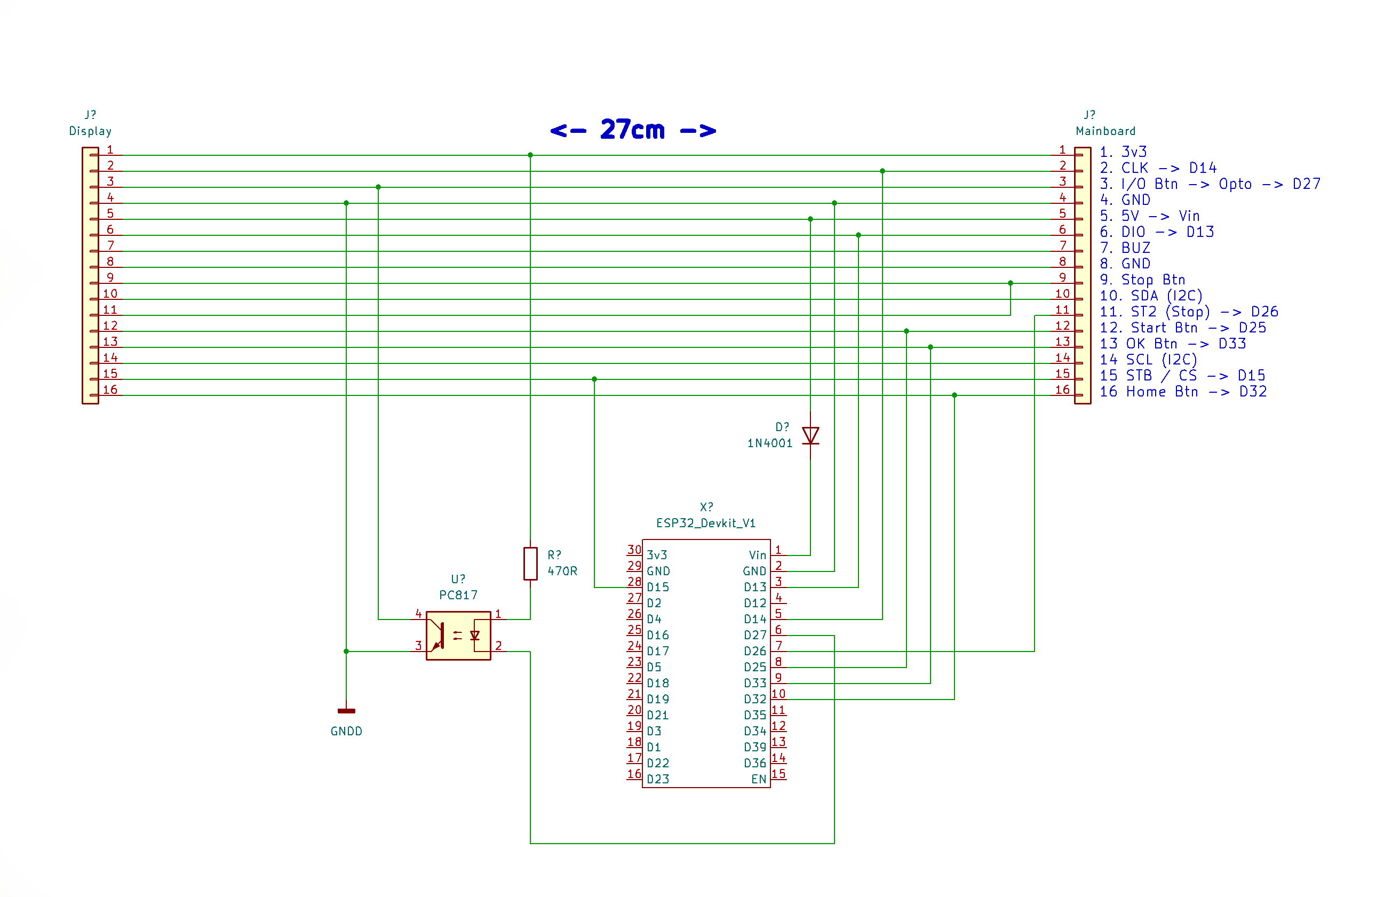
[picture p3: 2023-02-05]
pic/LX790 V1.1/Adapter Cable.png

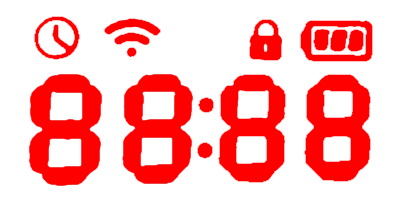
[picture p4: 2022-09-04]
docs/LX790_V1_1/Seg Display.jpg

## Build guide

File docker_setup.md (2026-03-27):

# LX790 ESP32 Docker Environment

This repository provides a comprehensive Docker environment for developing, building, and flashing the LX790 ESP32 project.

## Features
- **Python 3.12**: Modern Python environment.
- **PlatformIO**: Primary build system for this project.
- **Arduino CLI (v0.35.3)**: Alternative build system with `esp32:esp32` and `arduino:avr` cores.
- **ESP-IDF (v5.2)**: For low-level ESP32 development.
- **Node.js 20 & Gemini CLI**: Built-in AI-powered development assistance.
- **Build Tools**: Includes `cmake`, `ninja`, `dfu-util`, and `libusb-1.0-0`.

---

## 1. Setup

### Start the Container with Docker Compose
```bash
docker compose up -d
```
This will build and start the `lx790-gemini` container in the background.

### Start an Interactive Shell
```bash
docker compose exec -it lx790-gemini bash
```

---

## 2. Usage with PlatformIO (Recommended)

PlatformIO is the preferred way to manage dependencies and build this project.

### Build Project
```bash
docker compose exec lx790-gemini pio run
```

### Clean Build Files
```bash
docker compose exec lx790-gemini pio run -t clean
```

### Flash to Device
Ensure your ESP32 is connected and recognized (usually `/dev/ttyUSB0`).
Since Docker Compose doesn't automatically map your device, use a one-off `docker compose run` command for flashing:
```bash
docker compose run --rm --device=/dev/ttyUSB0 lx790-gemini pio run -t upload
```

#### Windows

Make sure that the USB is accessable to docker.
```PowerShell
usbipd list
usbipd bind --busid <BUSID>
usbipd attach --wsl --busid <BUSID>
```

---

## 3. Usage with Arduino CLI

If you prefer using the Arduino CLI directly for the `.ino` sketch:

### Compile Sketch
```bash
docker compose exec lx790-gemini \
    arduino-cli compile --fqbn esp32:esp32:esp32doit-devkit-v1 /workspace/src/LX790_ESP32.ino
```

### Upload Sketch
As with PlatformIO, use a one-off `docker compose run` command to access the hardware:
```bash
docker compose run --rm --device=/dev/ttyUSB0 lx790-gemini \
    arduino-cli upload -p /dev/ttyUSB0 --fqbn esp32:esp32:esp32doit-devkit-v1 /workspace/src/LX790_ESP32.ino
```

---

## 4. Usage with Gemini CLI

The environment includes the Gemini CLI for AI assistance. Your Gemini configuration is persisted in the `.gemini` folder in your project directory.

### Run Gemini CLI
```bash
docker compose exec -it lx790-gemini gemini-cli
```

---

## Troubleshooting & Tips

### Permission Denied on /dev/ttyUSB0
If you encounter permission issues when flashing, you might need to add your user to the `dialout` group or use `sudo` (not recommended).
Alternatively, temporarily change permissions:
```bash
sudo chmod 666 /dev/ttyUSB0
```

### Docker Compose Container Name
You can check the name of the running container with:
```bash
docker compose ps
```
The service name is `lx790-gemini`.

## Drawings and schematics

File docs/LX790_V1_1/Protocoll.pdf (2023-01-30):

# LX890 V1.1

## Display Cable

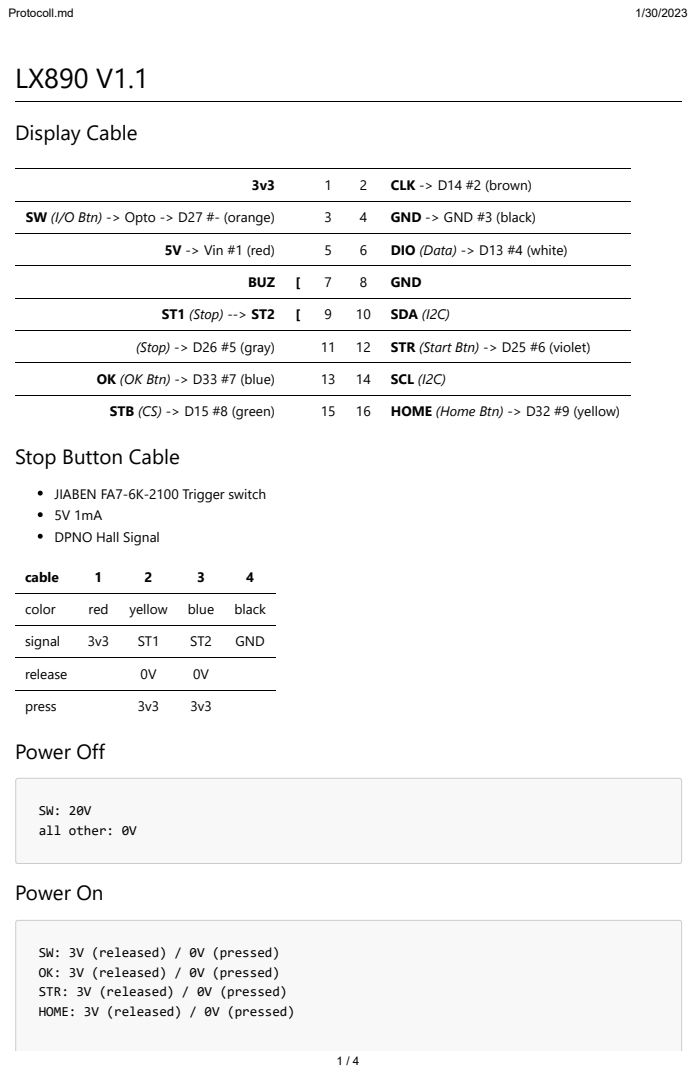
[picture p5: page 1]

## Display Controller: TM1668

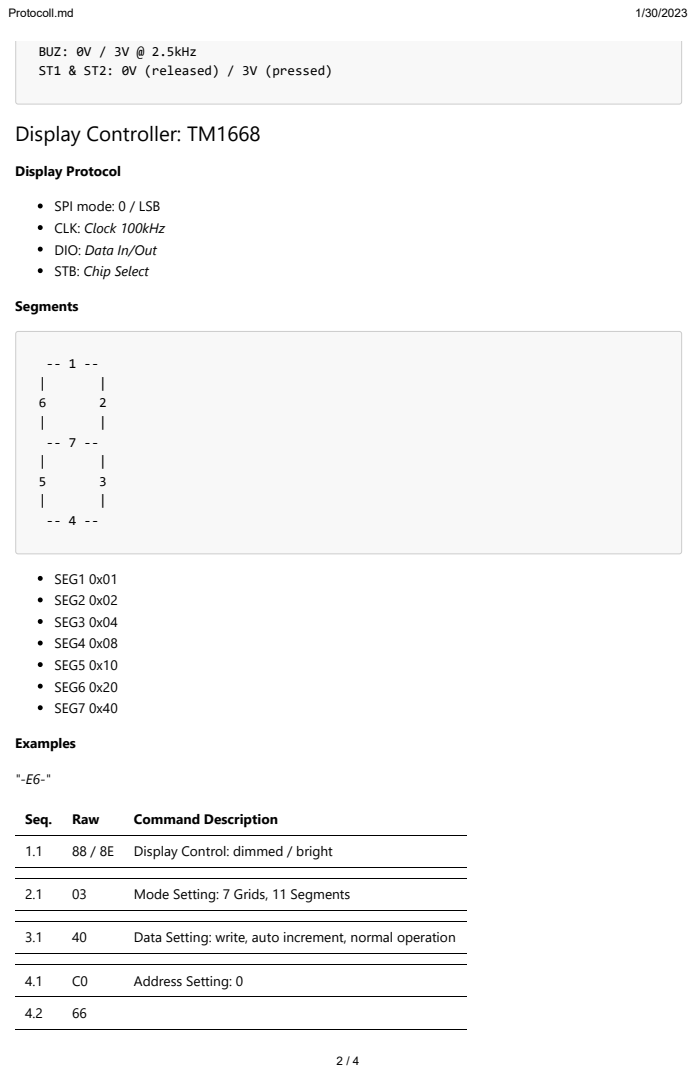
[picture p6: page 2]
BUZ: 0V / 3V @ 2.5kHz ST1 & ST2: 0V (released) / 3V (pressed); Display Protocol; Segments; SEG1 0x01 SEG2 0x02 SEG3 0x04 SEG4 0x08 SEG5 0x10 SEG6 0x20 SEG7 0x40; Examples; Seq. Raw; Command Description; 88 / 8E Display Control: dimmed / bright; Mode Setting: 7 Grids, 11 Segments; Data Setting: write, auto increment, normal operation; Address Setting: 0

SPI mode: 0 / LSB
CLK: Clock 100kHz
DIO: Data In/Out
STB: Chip Select

Seq. Raw | Command Description
4.3 | 00
4.4 | 60
4.5 | 00
4.6 | 64
4.7 | 00
4.8 | 26
4.9 | 00
4.10 | 26
4.11 | 00
4.12 | 26
4.13 | 00
4.14 | 0F
4.15 | 00

"-E1-"

Seq. Raw Command Description

1.1 | 8E | Display Control: bright
2.1 | 03 | Mode Setting: 7 Grids, 11 Segments
3.1 | 40 | Data Setting: write, auto increment, normal operation
4.1 | C0 | Address Setting: 0
4.2 | 62
4.3 | 00
4.4 | 64
4.5 | 00
4.6 | 64
4.7 | 00
4.8 | 22
4.9 | 00
4.10 | 22

Seq. Raw Command Description

4.11 | 00
4.12 | 22
4.13 | 00
4.14 | 0B
4.15 | 00

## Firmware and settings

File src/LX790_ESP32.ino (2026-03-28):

#include <Arduino.h>
#include <string.h>
#include <ArduinoJson.h>
#include <SPIFFS.h>
#include "LX790_util.h"

#include "config.h"


TaskHandle_t hTaskHW;   //Hardware: I2C, WiFi...
TaskHandle_t hTaskWeb;   //Web...

/**
 * @brief Main hardware and network management task.
 * 
 * This task handles the WiFi connection (Client or Captive Portal), 
 * processes hardware communication via the HAL, manages the command queue 
 * for robot actions, and synchronizes the robot state.
 * 
 * @param pvParameters Pointer to task parameters (unused).
 */
void TaskHW( void * pvParameters );

/**
 * @brief Web server task.
 * 
 * This task handles the web interface, serves static files, 
 * processes configuration updates, and provides API endpoints 
 * for remote control.
 * 
 * @param pvParameters Pointer to task parameters (unused).
 */
void TaskWeb( void * pvParameters );

SemaphoreHandle_t stateQueue = NULL;
QueueHandle_t cmdQueue = NULL;

LX790_Config config;

void setup()
{
  Serial.begin(115200);
  while (!Serial);
  Serial.println("\n\nLX79x_WiFi application started");
  Serial.print("Build date: "); Serial.print  (__DATE__);
  Serial.print(" time: "); Serial.println(__TIME__);

  if(!SPIFFS.begin(true))
    Serial.println(F("init SPIFFS error"));
  
  // read config
  config.captivePortal = false;
  config.portalTimeout = 10 * 60;

  if (!SPIFFS.exists("/index.html")) {
    Serial.println(F("ERROR: Failed to read filesystem"));
    Serial.println(F("!-!-!-! build & upload filesystem image !-!-!-!"));
  }

  File file = SPIFFS.open("/config.json", "r");

  // deserialize the JSON document
  JsonDocument doc;
  DeserializationError error = deserializeJson(doc, file);
  if (error)
    Serial.println(F("Failed to read file, using default configuration"));

  // import config
  config.hostname = doc["name"] | "LX790";
  strncpy(config.pin, doc["pin"] | "1234", 4);
  config.wifiEnabled = doc["wifiEnabled"] | true;
  config.wifiSSID = doc["wifiSSID"] | "SSID";
  config.wifiPassword = doc["wifiPassword"] | "";
  config.captivePortal = doc["captivePortal"] | true;
  config.portalTimeout = doc["portalTimeout"] | 600;
  config.portalPassword = doc["portalPassword"] | "";
  file.close();

  DEBUG_println("config");
  DEBUG_print("  name: "); DEBUG_println(config.hostname);
  DEBUG_print("  pin: "); DEBUG_println(config.pin);
  DEBUG_print("  wifiEnabled: "); DEBUG_println(config.wifiEnabled);
  DEBUG_print("  wifiSSID: "); DEBUG_println(config.wifiSSID);
  DEBUG_print("  wifiPassword: "); DEBUG_println(config.wifiPassword);
  DEBUG_print("  captivePortal: "); DEBUG_println(config.captivePortal);
  DEBUG_print("  portalTimeout: "); DEBUG_println(config.portalTimeout);
  DEBUG_print("  portalPassword: "); DEBUG_println(config.portalPassword);
  DEBUG_println("");

  stateQueue = xQueueCreate(2, sizeof(LX790_State));
  if (stateQueue == NULL) {
    Serial.println(F("init state queue error"));
    while(1) {}
  }

  cmdQueue = xQueueCreate(16, sizeof(CMD_Type));
  if (cmdQueue == NULL) {
    Serial.println(F("init command queue error"));
    while(1) {}
  }

  DEBUG_println("start TaskHW");
  xTaskCreatePinnedToCore(
    TaskHW,   // Function to implement the task -> I2C, WiFi
    "TaskHW", // Name of the task
    10000,   // Stack size in words
    NULL,    // Task input parameter
    1,       // Priority of the task
    &hTaskHW, // Task handle
    0);      // Core where the task should run

  delay(1000);

  DEBUG_println("start TaskWeb");
  xTaskCreatePinnedToCore(
    TaskWeb,   // Function to implement the task -> Webserver
    "TaskWeb", // Name of the task
    10000,   // Stack size in words
    NULL,    // Task input parameter
    1,       // Priority of the task
    &hTaskWeb, // Task handle
    1);      // Core where the task should run

}

void loop()
{
  //Core 1
  delay(1000);  // prevent loop from eating up resources
}

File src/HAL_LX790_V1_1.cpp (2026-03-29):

#include "config.h"
#ifdef HW_MODEL
#if HW_MODEL == LX790_V1_1

#include <ESP32SPISlave.h>
#include "LX790_util.h"

#include "HAL_LX790_V1_1.h"

/**
 * @brief Maps a BUTTONS enum value to its corresponding GPIO pin.
 * @param btn The button.
 * @return The GPIO pin number, or 0 if unknown.
 */
static inline byte getButtonPin(BUTTONS btn) {
  switch (btn) {
    case BTN_IO:
      return BTN_PIN_IO;
    case BTN_START:
      return BTN_PIN_START;
    case BTN_HOME:
      return BTN_PIN_HOME;
    case BTN_OK:
      return BTN_PIN_OK;
    case BTN_STOP:
      return BTN_PIN_STOP;
    default:
      return 0;
  }  
}

void HAL_buttonPress(BUTTONS btn) {
  byte pin = getButtonPin(btn);
  if ( btn == BTN_STOP ) {
    pinMode(pin, OUTPUT);
    digitalWrite(pin, 1);
  } else {
    pinMode(pin, OUTPUT);
    digitalWrite(pin, 0);
  }
  DEBUG_printf("button pressed (D%d)\n", pin);
}

void HAL_buttonRelease(BUTTONS btn) {
  byte pin = getButtonPin(btn);
  if ( btn == BTN_STOP ) {
    pinMode(pin, OUTPUT);
    digitalWrite(pin, 0);
  } else {
    pinMode(pin, INPUT);
  }
  DEBUG_printf("button released (D%d)\n", pin);
}

/**
 * @brief Decodes raw TM1668 SPI data into robot state.
 * Extracts segment patterns for digits, icons (clock, lock, battery, wifi) 
 * and dots/colons.
 * @param raw The 14 bytes of raw data from TM1668.
 * @param state Reference to the state structure to be updated.
 * @return true if decoding was successful and data is valid, false otherwise.
 */
bool decodeTM1668(const uint8_t raw[14], LX790_State &state) {
  byte val;
  bool updated = false;

  // LCD digits
  uint16_t segCnt = 0;
  bool error = false;
  for (int i=0; i<4; i++) {
    byte segments = 0;
    byte mask = 1 << i;
    for (int j=0; j<7; j++) {
      segments |= (raw[j*2] & mask) ? (1<<j) : 0;
    }
    if ( state.segments[i] != segments ) updated = true;
    state.segments[i] = segments;
    byte seg = segments;
    while (seg) {
      if (seg & 0x01)
        segCnt++; 
      seg = seg >> 1;
    }

    if ( decodeChar(segments) == '#' ) {
      // error reading display
      error = true;
    }
  }
  // return if error on decoding digits, if exactly 1 segment active -> running (no error)
  if ( error && segCnt != 1 )
    return false;

  for (int i=0; i<4; i++) {
    state.digits[i] = decodeChar(state.segments[i]);
  }

  // clock
  val = bitRead(raw[0*2], 4) | bitRead(raw[1*2], 4);
  if ( state.clock != val ) updated = true;
  state.clock = val;

  // wifi
  // wifi is output / state.wifi = bitRead(raw[2*2], 4) | bitRead(raw[3*2], 4);

  // lock
  val = bitRead(raw[4*2], 4) | bitRead(raw[5*2], 4);
  if ( state.lock != val ) updated = true;
  state.lock = val;

  // battery
  val = bitRead(raw[2*2], 6) + bitRead(raw[1*2], 6) + bitRead(raw[0*2], 6);
  if ( state.battery != val ) updated = true;
  state.battery = val;

  // dots
  val = ' ';
  if ( bitRead(raw[3*2], 6) )
      val = '\'';
  if ( bitRead(raw[4*2], 6) )
      val = '.';
  if ( bitRead(raw[3*2], 6) && bitRead(raw[4*2], 6) )
      val = ':';
  if ( state.point != val ) updated = true;
  state.point = val;

  if ( updated ) {
    state.updated = true;
    state.updateTime = millis();
  }

  return true;
}

ESP32SPISlave tm1668;
const uint8_t spi_slave_rx_buf_size = 16;
const uint8_t spi_slave_rx_buf_slots = 4;
uint8_t spi_slave_rx_buf[spi_slave_rx_buf_size*spi_slave_rx_buf_slots];
uint8_t spi_slave_rx_buf_read_pos = 0;

void HAL_setup()
{
  // init HW Communication
  tm1668.setDataMode(SPI_MODE1);
  tm1668.setSlaveFlags(SPI_SLAVE_BIT_LSBFIRST);
  tm1668.setQueueSize(4);
  tm1668.begin(VSPI, CLK_PIN_DISPLAY, VSPI_MISO, DIO_PIN_DISPLAY, CS_PIN_DISPLAY);

  pinMode(CS_PIN_DISPLAY, INPUT);
  pinMode(DIO_PIN_DISPLAY, INPUT);
  pinMode(CLK_PIN_DISPLAY, INPUT);

  digitalWrite(BTN_PIN_IO, 0);
  digitalWrite(BTN_PIN_START, 0);
  digitalWrite(BTN_PIN_HOME, 0);
  digitalWrite(BTN_PIN_OK, 0);
  digitalWrite(BTN_PIN_STOP, 0);
  pinMode(BTN_PIN_IO, INPUT);
  pinMode(BTN_PIN_START, INPUT);
  pinMode(BTN_PIN_HOME, INPUT);
  pinMode(BTN_PIN_OK, INPUT);
  pinMode(BTN_PIN_STOP, OUTPUT);
}

void HAL_loop(LX790_State &state) {
  static LX790_State oldState = {0};
  static long btnHomeTime = -1;
  static byte btnHomeVal = -1;

  // read SPI buffer (LCD data)
  int len = tm1668.numBytesReceived();
  while (len) {
    uint8_t brightness;
    uint8_t *ptr = spi_slave_rx_buf + spi_slave_rx_buf_read_pos;

    #if DEBUG_SERIAL_PRINT
    {
      DEBUG_print("SPI RAW: ");
      for (int i=0; i<spi_slave_rx_buf_size; i++) {
        char hex[4];
        sprintf(hex, "%02X ", ptr[i]);
        DEBUG_print(hex);
      }
      DEBUG_printf(" (len: %d)\n", len);
    }
    #endif

    spi_slave_rx_buf_read_pos += spi_slave_rx_buf_size;
    if ( spi_slave_rx_buf_read_pos >= spi_slave_rx_buf_size*spi_slave_rx_buf_slots )
      spi_slave_rx_buf_read_pos = 0;
    uint8_t cmd = ptr[0];

    switch ( cmd & DISPLAY_CMD_MASK ) {
      case DISPLAY_CMD_CONTROL:
      brightness = bitRead(cmd, 4) ? 0 : (cmd & 0xE) + 1;
        if (state.brightness != brightness) 
        {
          state.brightness = brightness;
          state.updated = true;
          state.updateTime = millis();
        }
        break;

      case DISPLAY_CMD_MODE_SET:
      case DISPLAY_CMD_DATA_SET:
      // ignore
        break;

      case DISPLAY_CMD_ADDRESS:
        if ( len == 15) {
          decodeTM1668(ptr+1, state);
        }
        break;
    }
    len = tm1668.numBytesReceived();
  }

  // start data read via SPI
  if ( tm1668.hasTransactionsCompletedAndAllResultsHandled() ) {
    spi_slave_rx_buf_read_pos = 0;

    size_t buf_ptr = 0;
    tm1668.queue(NULL, &spi_slave_rx_buf[buf_ptr], spi_slave_rx_buf_size); buf_ptr += spi_slave_rx_buf_size;
    tm1668.queue(NULL, &spi_slave_rx_buf[buf_ptr], spi_slave_rx_buf_size); buf_ptr += spi_slave_rx_buf_size;
    tm1668.queue(NULL, &spi_slave_rx_buf[buf_ptr], spi_slave_rx_buf_size); buf_ptr += spi_slave_rx_buf_size;
    tm1668.queue(NULL, &spi_slave_rx_buf[buf_ptr], spi_slave_rx_buf_size); buf_ptr += spi_slave_rx_buf_size;
    tm1668.trigger();
  }

  // press "HOME" button for 10 seconds to start captive portal
  unsigned long time = millis();
  byte pin = getButtonPin(BTN_HOME);
  byte val = digitalRead(pin);
  if ( btnHomeVal != val ) {
    DEBUG_print("button home: "); DEBUG_println(val);
    btnHomeVal = val;
    btnHomeTime = time;
  }
  
  if ( !config.captivePortal && state.brightness> 0 && btnHomeVal == 0 && ( (time-btnHomeTime) > 9000) ) {
    btnHomeTime = time; // reset timer for home botton to prevent multiple execution
    Serial.println("home button pressed 10s -> activate captive portal");
    CMD_Type xcmd;
    xcmd = {CMD_Type::DISCONNECT, 0}; xQueueSend(cmdQueue, &xcmd, 0);
    xcmd = {CMD_Type::WAIT, 1000}; xQueueSend(cmdQueue, &xcmd, 0);
    xcmd = {CMD_Type::WIFI_PORTAL, 0}; xQueueSend(cmdQueue, &xcmd, 0);
  }

}


#endif
#endif

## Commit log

2022-09-04 switch to ESPAsyncWebServer
2022-09-04 SPI communication
2022-09-05 switch back to Sync WebServer sync speed test -> 200ms
2022-09-11 - update STOP button - OTA - charging mode
2022-09-22 add Cable Adapter schematics
    [Adapter Cable.kicad_sch]
2022-09-22 switch to VSPI
2022-09-23 animate charging
2023-01-30 update documentation
    [Adapter Cable.kicad_sch]
2023-02-05 add NTP time
    [Adapter Cable.kicad_sch]
2023-02-06 fix error handling for missing config.h file
    [HAL_LX790_V1_0.cpp, HAL_LX790_V1_0.h, HAL_LX790_V1_1.cpp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]
2023-02-20 switch to config.json
2023-03-05 enable captive portal on "HOME" button press
2023-07-02 fix rollback to old firmware after OTA update
    [TaskHW.cpp]
2023-07-03 fix auto pin unlock
    [LX790_util.cpp]
2023-07-05 overwritte state to fix CHARGE / DOCKED toggling
    [LX790_util.cpp]
2023-07-09 try to detect mis-formed SPI messages -> ignore message
2023-07-10 overwrite LX790_CHARGING -> LX790_DOCKED (charging detection is not reliable)
2023-07-14 switch to running mode only, if not in error or rain mode
    [LX790_util.cpp]
2025-05-04 update debug prints
2025-05-08 migrate to latest library versions - CRC 0.3.1 -> 1.0.3 - ESP32SPISlave 0.2.0 -> 0.6.8 - ArduinoJson 6.20.1 -> 7.4.1
2026-03-29 feat(hal): add raw SPI dump for TM1668 debugging
